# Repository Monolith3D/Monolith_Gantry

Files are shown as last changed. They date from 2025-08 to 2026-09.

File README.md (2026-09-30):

[][cc-by-nc-sa]

# Monolith Gantry R1
> [!IMPORTANT]
> **Step-by-step build guides for the printed and sheet metal versions are not yet available.**
> 
> **The sheet metal version is more difficult to build than what the average Voron user is used to. Please evaluate the required patience and skill levels before proceeding.**



## What's this?
This is a performance-oriented, configurable gantry platform for Voron 2.4 and Trident.

### [Official LDO Milled Gantry Kits](https://github.com/Monolith3D/LDO_Monolith_Gantry_Kits)

## Start Here

- [Gantry Configurator](https://configurator.monolith3d.xyz/) for configuration, files, and the selected BOM.
- [Build guides and assembly notes](Docs/)
- [Toolheads for Monolith](https://github.com/Monolith3D/Toolheads_for_Monolith) for compatible toolheads, belt clamps, and design guidelines.
- [FAQ](FAQ.md) for configuration, sourcing, and assembly questions.

### Drive configurations:
- 2WD
- AWD

### Belt widths:
- 6mm
- 9mm

 ### Materials:
- Printed
- Sheet metal
- Milled kits

## What's new with Monolith R1?
- Updated styling
- More shared parts between 6 and 9mm
- Sheet metal options
- Can fit into a stock 2020 frame at the cost of some Y-overtravel with the added no-protrusion mode
- Much better tensioner travel
- No toothed idlers
<br/>

> [!NOTE]
> **If you have questions or want to stay more up-to-date with Monolith, consider joining the dedicated Discord server.**
>
> Join the Discord (https://discord.gg/monolith3d)
>
> **If you would like to see more of this and other projects in the future, consider supporting Monolith on Patreon.**
>
> Support Monolith on Patreon (https://www.patreon.com/monolith3d)

## Design goals
- The shortest and the simplest belt path possible with AWD compatibility
- The shortest moment arms possible for increased rigidity even when reusing hardware and motion parts
- Double shear steppers and live shaft idlers for higher belt tensions and better reliability
- Good-looking design
- Cheap BOM

## Performance expectations
**2WD:** Due to the 10-15cm shorter belt path, with stiffer and lighter XY-joints the printer should perform similarly to a 50mm smaller one equipped with the same X-axis setup.

**AWD:** It doesn't come at the cost of adding 20cm belt length and idlers, so input shaper scaling can be close to +100% compared to 2WD due to the truly halved effective belt length. But only when no toolhead or frame bottlenecks are limiting its scaling.

**9mm belts:** Wider belts can offer an additional 50% input shaper scaling on top of what's described above.

## What's the catch?
- you have to build a well-balanced system: the increased effective belt stiffness with higher-end gantry configurations will amplify toolhead and frame rigidity issues
- Some toolheads are not yet compatible because of the different belt path
- Z-chain relocation or Z-umbilical is needed on V2
- Trident rear vertical extrusion brackets have to be rotated by 180 degrees or swapped to regular 2020 brackets based on the gantry configuration

## Acknowledgement
We want to thank:

- **[Sy-Noon](https://synoon.portfoliobox.net/)** for the awesome logo and feedback on general aesthetics
- **itsK** for the configurator website
- **ifp, iniqy, krankydonkey, MoneyShot, Nicket, tktktktk, Zakfarias, Scarecrow, The Adeo** for testing and good feedback
- **ZaMarin** and **Renovic** for the FAQ
- **Armchair Heavy Industries** for the exposure and the moderation help I got in their user-project space
- **VoronDesign** for making V2.4 and Trident and for starting us on this journey
- anyone who helped us along the way

<br/><br/><br/><br/>
This work is licensed under a
[Creative Commons Attribution-NonCommercial-ShareAlike 4.0 International License][cc-by-nc-sa].

[][cc-by-nc-sa]

[cc-by-nc-sa]: http://creativecommons.org/licenses/by-nc-sa/4.0/
[cc-by-nc-sa-image]: https://licensebuttons.net/l/by-nc-sa/4.0/88x31.png
[cc-by-nc-sa-shield]: https://img.shields.io/badge/License-CC%20BY--NC--SA%204.0-lightgrey.svg

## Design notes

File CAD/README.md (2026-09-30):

### The [Gantry Configurator](https://configurator.monolith3d.xyz/) will give you the links to the files you need for your build!

## Changelog

### 15.06.2025

- 695 W5 bearing support
- minor visual changes
- S45R long-shafted steppers in CAD
- subassembly fixes

### 10.06.2025

- sheet metal tensioner wire delete
- gantry-mounted X-endstop option

### 28.01.2025

- fixed subassembly origins
- fixed some naming oopsies
- ditched the printed alignment helpers for the sheet metal version
- more corner reliefs on motor mount plates
- smaller assembly/BOM fixes

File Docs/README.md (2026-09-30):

# Build guides and assembly notes

Step-by-step build guides for the printed and sheet metal R1 versions are not yet available. Use the [Gantry Configurator](https://configurator.monolith3d.xyz/) to select the configuration, files, and BOM for your build, and the [FAQ](../FAQ.md) for sourcing, print settings, and assembly notes.

Sheet metal builds require bearing-hole reaming, countersinking, and more involved assembly. Review the [printed and sheet metal comparison](../FAQ.md#should-i-choose-printed-or-sheet-metal) before choosing a build path.

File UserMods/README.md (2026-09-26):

# User Mods

This folder is for community-made additions, adaptations, and compatibility parts for the Monolith Gantry.

User mods are not official Monolith Gantry files unless stated otherwise. Check the mod author, target printer, gantry variant, drive layout, fit layout, and toolhead assumptions before printing or ordering parts.

Use the folder structure `username/usermod_name` for new user mods.

Good user mod folders should include:

- A short `README.md` explaining what the mod does
- Clear compatibility notes for V2 or VT, 2WD or AWD, and NP or FT where relevant
- STL, CAD, image, and BOM files needed to understand the mod
- Assembly notes or warnings if the mod changes belt path, endstops, travel, docks, panels, or toolhead clearance
- Credit and license notes when the mod reuses work from another project

Use user mods at your own risk. They may not receive updates when the main Monolith Gantry files change.

## Existing User Mods

| Mod | Author | What it does |
| --- | --- | --- |
| usermod_name | username | Briefly describe what the mod adds, adapts, or changes. |
| [Monolith cube](SilencedFrost/) | SilencedFrost | Provides a Monolith cube STL. |
| [X endstop extender and rear Z chain](OlBamboozler/) | OlBamboozler | Adds an Xol-carriage X endstop extender and a rear Z-chain extrusion mount for wiring cleanup. |
| [V2 MGN9C Z Joints](Iroh/V2%20MGN9C%20Z%20Joints/) | Iroh | Provides V2 Z-joint files for MGN9C Z rails/carriages, including printed, hybrid, and SLM files. |
| [SLM MGN12H XY-joints](CloakedWayne/SLM_MGN12H_XY_joints/) | CloakedWayne | Unmaintained, unsupported adaptation for MGN12H Y rails using SLM XY-joints. MGN9H carriages are recommended instead. |
| [XY Joints compatible with Fysetc CNC Stealthchanger Shuttle](dderg/XY%20Joints%20compatible%20with%20Fysetc%20CNC%20Stealthchanger%20Shuttle/) | dderg | Moves the X beam back 2 mm so 9 mm belts can clamp from the front of the Fysetc CNC Stealthchanger Shuttle. |
| [Monolith K1 Max](KhaymKhaym/Monolith%20K1%20Max/) | KhaymKhaym and BootyCallJones | Adapts the Monolith Gantry to the Creality K1 Max with CAD, panel DXF, gantry reinforcement DXF, and print files. |
| [Monolith VZ330](KhaymKhaym/Monolith%20VZ330/) | KhaymKhaym and Kaifas | Adapts the Monolith Gantry to the VZ330 with CAD-based assembly instructions. |
| [Sheet-Metal Monolith 3030 Mod](WolfKnifeLaserBacon/) | WolfKnifeLaserBacon | Adapts Sheet-Metal Monolith to 3030 Extrusions with CAD and BOM, changes required, etc |
|  | your name here :) |  |

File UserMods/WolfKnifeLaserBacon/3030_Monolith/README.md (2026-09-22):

# Monolith 3030 Sheet Metal Gantry

## Rat Rig V-Core 3.1 Modification

This user mod adapts the **Monolith gantry system** for use with a **Rat Rig V-Core 3.1** using a 3030-based sheet-metal gantry arrangement.

The current design is being developed around a **V-Core 3.1 500**, but other V-Core 3.1 sizes should be adaptable by changing the required extrusion, linear-rail, and belt lengths.

Most assembly procedures and hardware remain based on the standard Monolith BOM. This repository primarily contains the parts, dimensions, and hardware changes required to adapt Monolith to the V-Core 3.1 frame, along with additional information gathered during development.

For current development notes, reference information, and questions, see the dedicated Discord discussion:

💬 [Monolith V-Core 3.1 User Mod Development Thread](https://discord.com/channels/1227971059764953230/1537888786921427094)

---

## Current Status

- **Current printer:** Rat Rig V-Core 3.1 500
- **Drive configuration:** AWD
- **Gantry configuration:** Standard Monolith rail arrangement
- **X beam:** 594 mm
- **X MGN-12H linear rail:** 570 mm - Monolith standard
- **Y MGN-12C linear rails:** 550 mm - stock VC3.1
- **Development status:** Work in progress

The current release is designed around an **AWD Monolith configuration**.

A 2WD version will be adapted in a future revision.

No single toolhead has been selected as the required configuration. One of the goals of the project is to support multiple compatible toolhead and tool-changing options where practical.

---

# Design Direction

After spending considerably more time in CAD and experimenting with several different rail arrangements, the **standard Monolith rail configuration has proven to be the most practical and optimal solution for the V-Core 3.1**.

Several alternatives were investigated, including:

- Stock V-Core 3.1 Y-rail locations
- Top-mounted Y rails
- Bottom-mounted Y rails
- Mixed top/bottom Y-rail arrangements
- Top-mounted X rail

While some of these arrangements are technically possible, the required offsets, clearance compromises, loss of usable travel, increased complexity, and additional custom geometry outweigh their advantages.

In particular, a **top-mounted X rail is not a practical solution for this conversion** without introducing compromises that defeat much of the purpose of using Monolith in the first place.

Because of this, development will now focus solely on the **standard Monolith rail arrangement** rather than maintaining multiple substantially different gantry variants.

### Going forward, development will focus on:

- Standard Monolith rail geometry
- Different belt widths and belt configurations
- AWD
- 2WD adaptation
- Multiple toolhead options
- Tool changer compatibility
- Additional V-Core 3.1 frame sizes where practical
- Additional 3030 extrusion based printers

The goal is to refine one solid Monolith-based architecture rather than divide development between several compromised rail configurations.

---

# X Travel

One unavoidable difference between the stock V-Core 3.1 gantry and the Monolith 3030 conversion is the available X-axis travel.

For the **V-Core 3.1 500**:

| Configuration | X Linear Rail | Approximate X Travel |
| --- | ---: | ---: |
| Stock V-Core 3.1 | 600 mm | ~500–520 mm |
| Monolith 3030 | 570 mm | ~470 mm conservative |

The Monolith conversion therefore sacrifices approximately **30–50 mm of total X travel**, depending on the exact stock configuration and toolhead geometry.

The current **~470 mm** figure should be considered a conservative design target rather than an absolute mechanical limit.

Actual usable travel may vary slightly depending on:

- Toolhead
- X carriage
- Endstop arrangement
- Probe placement
- Tool changer hardware
- Belt attachment geometry
- Required frame and enclosure clearances

For most applications, the reduction in X travel is considered an acceptable tradeoff for maintaining the standard Monolith geometry and its associated simplicity, belt routing, rigidity, and performance.

Toolhead-specific travel information will be documented as configurations are tested.

---

# VC3.1 500 Dimensions

## Standard Monolith Configuration

This is the supported and actively developed configuration.

| Component | Length |
| --- | ---: |
| X beam | 594 mm |
| X linear rail | 570 mm |
| Y linear rails | 550 mm — stock VC3.1 |
| Rear extrusion | 510 mm |
| Expected X travel | ~470 mm conservative |

Additional dimensions will be added as the design is finalized and verified.

---

# BOM

Most hardware remains standard Monolith.

The following lists the hardware currently identified for the **3030 V-Core 3.1 conversion**.

## 9 mm Belt Configuration

### Belting

| Qty | Part |
| ---: | --- |
| 5.8m | 9 mm GT2 belt |

Final belt lengths will be added after the belt path and tensioning requirements have been finalized.

### Bearings, Pins, and Spacers

| Qty | Part |
| ---: | --- |
| 6 | 695 bearing |
| 24 | F695 flanged bearing |
| 2 | 0.2 mm shim |
| 22 | 0.5 mm shim |
| 14 | 1 mm shim |
| 6 | D5 × 40 smooth pin |
| 4 | D5 × 5 compression spring |
| 4 | M3 × D5 × 30 round standoff |
| 14 | M3 × D6 × 30 spacer |
| 2 | M5 × D10 × 5 shaft collar |
| 16 | M5 × D8 × 5 spacer |

### Pulleys

| Qty | Part |
| ---: | --- |
| 4 | GT2 20T 9 mm pulley |
| 4 | GT2 20T 9 mm pulley, de-hubbed |

### Set Screws and Nuts

| Qty | Part |
| ---: | --- |
| 8 | M4 × 2.5 set screw |
| 4 | M3 hex nut |

### M3 Hardware

| Qty | Part |
| ---: | --- |
| 24 | M3 washer |
| 8 | M3 × 4 BHCS |
| 20 | M3 × 6 BHCS |
| 6 | M3 × 6 FHCS |
| 6 | M3 × 8 BHCS |
| 2 | M3 × 8 FHCS |
| 4 | M3 × 40 BHCS |
| 14 | M3 × 45 BHCS |

### M5 Hardware

| Qty | Part |
| ---: | --- |
| 6 | M5 2020 T-nut |
| 8 | M5 washer |
| 6 | M5 × 8 BHCS |
| 2 | M5 × 30 BHCS |

### M6 / 3030 Specific Hardware

| Qty | Part |
| ---: | --- |
| 16 | M6 3030 T-nut |
| 16 | M6 washer |
| 16 | M6 × 10 BHCS |

---

## 10 mm Belt Configuration

A **10 mm belt configuration** is also planned.

### Belting

| Qty | Part |
| ---: | --- |
| TBD | 10 mm GT2 belt |

Additional pulley, bearing, spacer, and hardware requirements will be documented once the 10 mm configuration has been finalized and tested.

---

# Toolhead Compatibility

The 3030 Monolith conversion is not intended to be locked to a single toolhead.

Development will include evaluation and documentation of compatible toolhead configurations as they are modeled and tested.

Because toolhead geometry directly affects available travel, each supported configuration may have slightly different:

- Maximum X travel
- Maximum Y travel
- Probe clearance
- Endstop position
- Belt attachment position
- Frame clearance
- Docking clearance

Where possible, toolhead-specific travel limits and required parts will be documented separately.

---

# Tool Changer Compatibility

Tool changer compatibility is an active area of development.

The standard Monolith rail arrangement provides the most sensible foundation for investigating tool changing without creating separate gantry architectures for each configuration.

Future development may include:

- Tool docks
- Toolhead-specific carriages
- Dock mounting solutions
- Umbilical management
- CAN toolhead support
- Parking clearance
- Automatic tool changing
- Toolhead-specific travel limits

Tool changer support should currently be considered **experimental until individual configurations have been physically tested**.

---

# Compatibility

Currently designed around:

- Rat Rig V-Core 3.1
- 500 mm VC3.1 frame
- Standard Monolith gantry geometry
- AWD
- 3030 extrusion
- 9 mm GT2 belts
- 570 mm X linear rail
- 550 mm Y linear rails

Other V-Core 3.1 sizes should be adaptable by changing the appropriate extrusion, linear-rail, and belt lengths.

## Planned Development

Current development priorities include:

- 10 mm belts
- Additional belt configurations
- Additional toolhead options
- Tool changer compatibility
- 2WD adaptation
- Additional V-Core 3.1 frame sizes
- Verified travel measurements
- Final belt lengths
- Assembly documentation

Alternate top/bottom Y-rail arrangements and top-mounted X-rail configurations are **not currently planned for further development**.

---

# Assembly

Unless otherwise noted, assembly follows the standard Monolith assembly procedure and BOM.

Only components or assembly steps that differ from standard Monolith will be documented here.

Builders should verify:

- Belt alignment
- Pulley and bearing spacing
- Linear-rail alignment
- X/Y squareness
- Gantry clearance
- Toolhead clearance
- Endstop location
- Full X/Y travel

before operating the printer at high acceleration or speed.

---

# Initial ChatGPT Estimated Belt Length Comparison

| Belt configuration | Approximate length per belt | Approximate total for two belts |
|---|---:|---:|
| Stock Rat Rig V-Core 3.1 500 | 2,681 mm | 5,362 mm |
| 9 mm AWD arrangement | 2,589 mm | 5,178 mm |
| Difference | 92 mm shorter | 183 mm shorter |

The **9 mm AWD belts are approximately 3.4% shorter** than the stock Rat Rig V-Core 3.1 500 belts.

## Recommended Initial Cut Lengths

- **Stock V-Core 3.1 500:** approximately 2.70 m per belt
- **9 mm AWD arrangement:** approximately 2.61–2.62 m per belt

A **6 m roll of 9 mm GT2 belt** is sufficient for either configuration.

---

# Notes

This project is under active development.

Dimensions, hardware quantities, belt lengths, and CAD may change as the design is built and tested.

Parts marked **TBD** have not yet been finalized and should not be treated as manufacturing dimensions.

The **~470 mm X travel figure is currently a conservative estimate** for the V-Core 3.1 500 Monolith configuration. Final usable travel will depend partially on the selected toolhead and associated hardware.

If you build or adapt this mod for another V-Core 3.1 size, contributions, measurements, testing, and feedback are welcome.

Find me everywhere — literally — on Discord:

**WolfKnifeLaserBacon**

---

## Special Thanks

Special thanks to the [**Monolith community**](https://discord.gg/monolith3d) on Discord and to **CloakedWayne** for the development of the **Monolith gantry** — the de facto solution for speed, simplicity, and quality.

Additional thanks to:

- **Maurice** — Testing and confirmations
- **[your name here / USERNAME]** — [CONTRIBUTION]

The 3030 Monolith would not be where it is today without the ideas, feedback, testing, and support contributed along the way.

Thank you to everyone who helped turn the concept into a finished design.

---

## Support Me

**NOT required, but very much appreciated!!**

If you'd like to support my work and future development, you can do so through Ko-fi:

[Support me on Ko-fi](https://ko-fi.com/wolfknifelaserbacon)

Every bit of support helps with continued development, prototyping, testing, and future projects.

Thank you!

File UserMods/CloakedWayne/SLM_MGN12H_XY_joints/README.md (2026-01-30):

# SLM MGN12H XY-Joints
> [!WARNING]
> **This is only a deeply flawed user mod and a dead end, not an officially supported configuration. It won’t receive any updates. Do it at your own risk! You are definitely better off getting 9Hs for your build.**

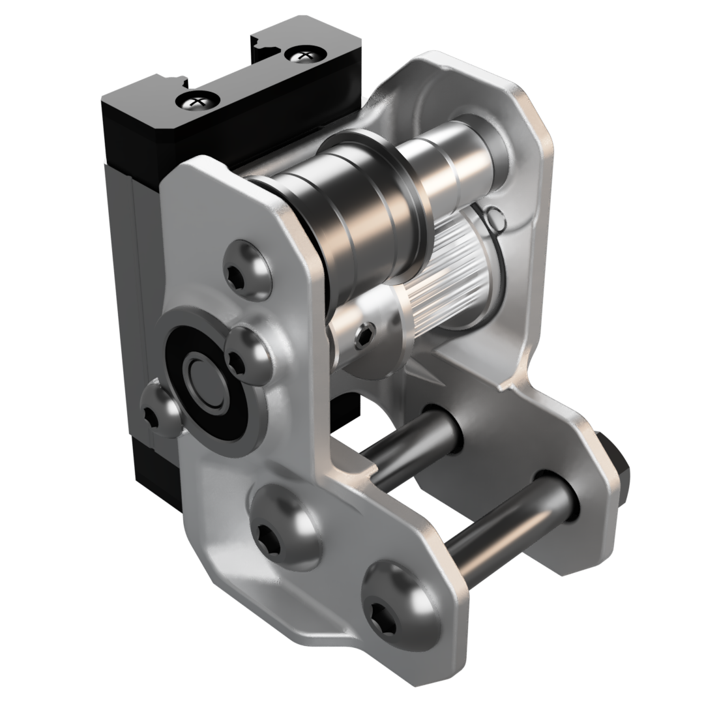
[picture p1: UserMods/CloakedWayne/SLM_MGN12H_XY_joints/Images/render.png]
Render

### Pros:
- You get MGN12Hs on Y with the unmodified Monolith belt path and without X-travel loss.
### Cons:
- Due to space constraints, the SLM part has to be really thin, and it’s very prone to warping.
- It requires a lot of post-processing, and you have to make sure the mounting surface is flat when it’s completely assembled.
- Hard to assemble and align.
- More severe bimetallic expansion, 2040 Y-extrusions, and/or backers are required.
- No performance advantage compared to MGN9H.
## Assembly

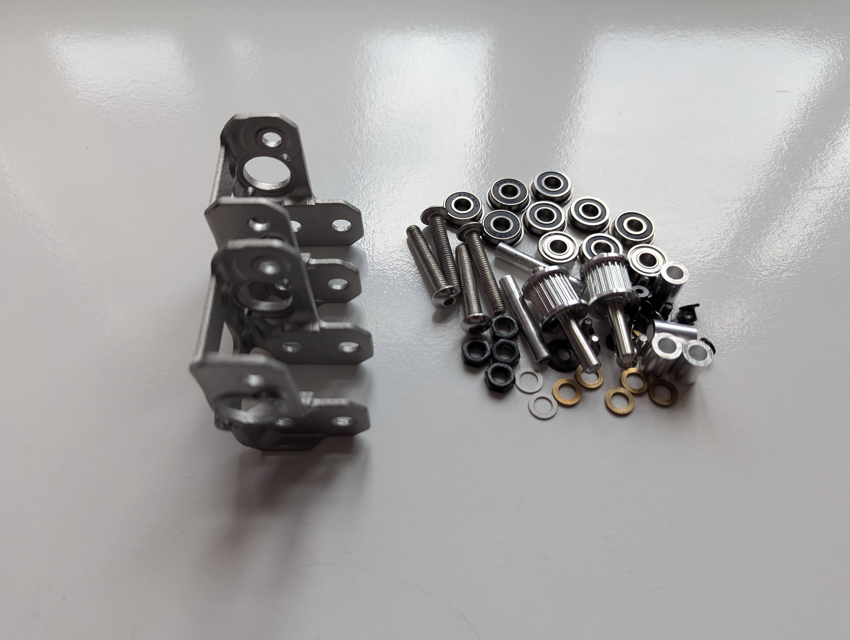
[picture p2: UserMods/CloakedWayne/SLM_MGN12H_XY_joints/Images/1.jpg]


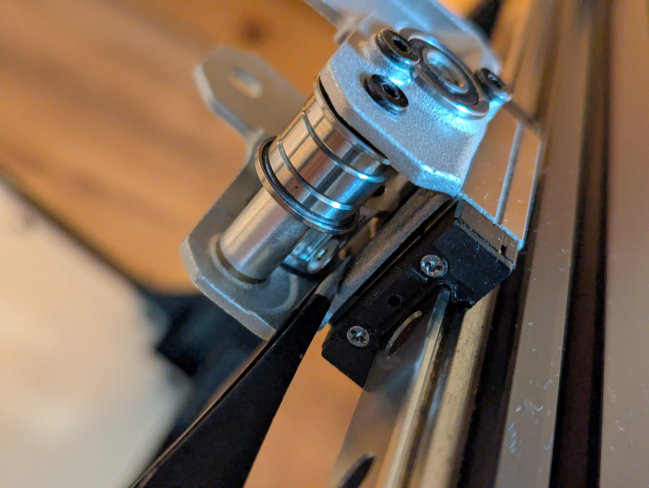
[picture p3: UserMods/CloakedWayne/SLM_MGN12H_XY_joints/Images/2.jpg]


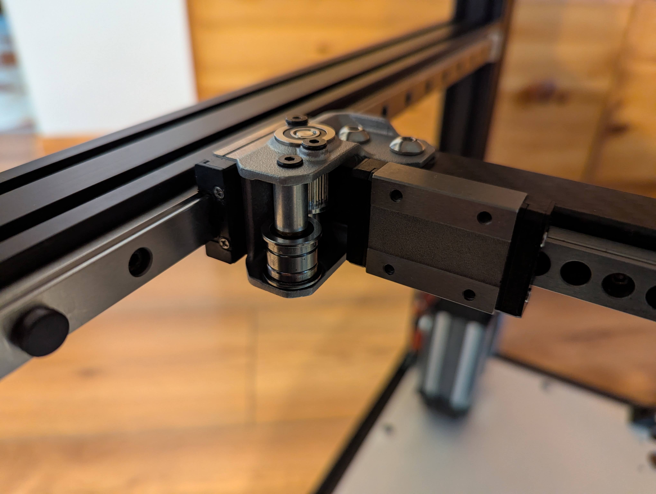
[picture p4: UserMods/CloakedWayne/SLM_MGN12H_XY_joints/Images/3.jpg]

## Vs. LDO MGN9H milled XY-joints in the same environment

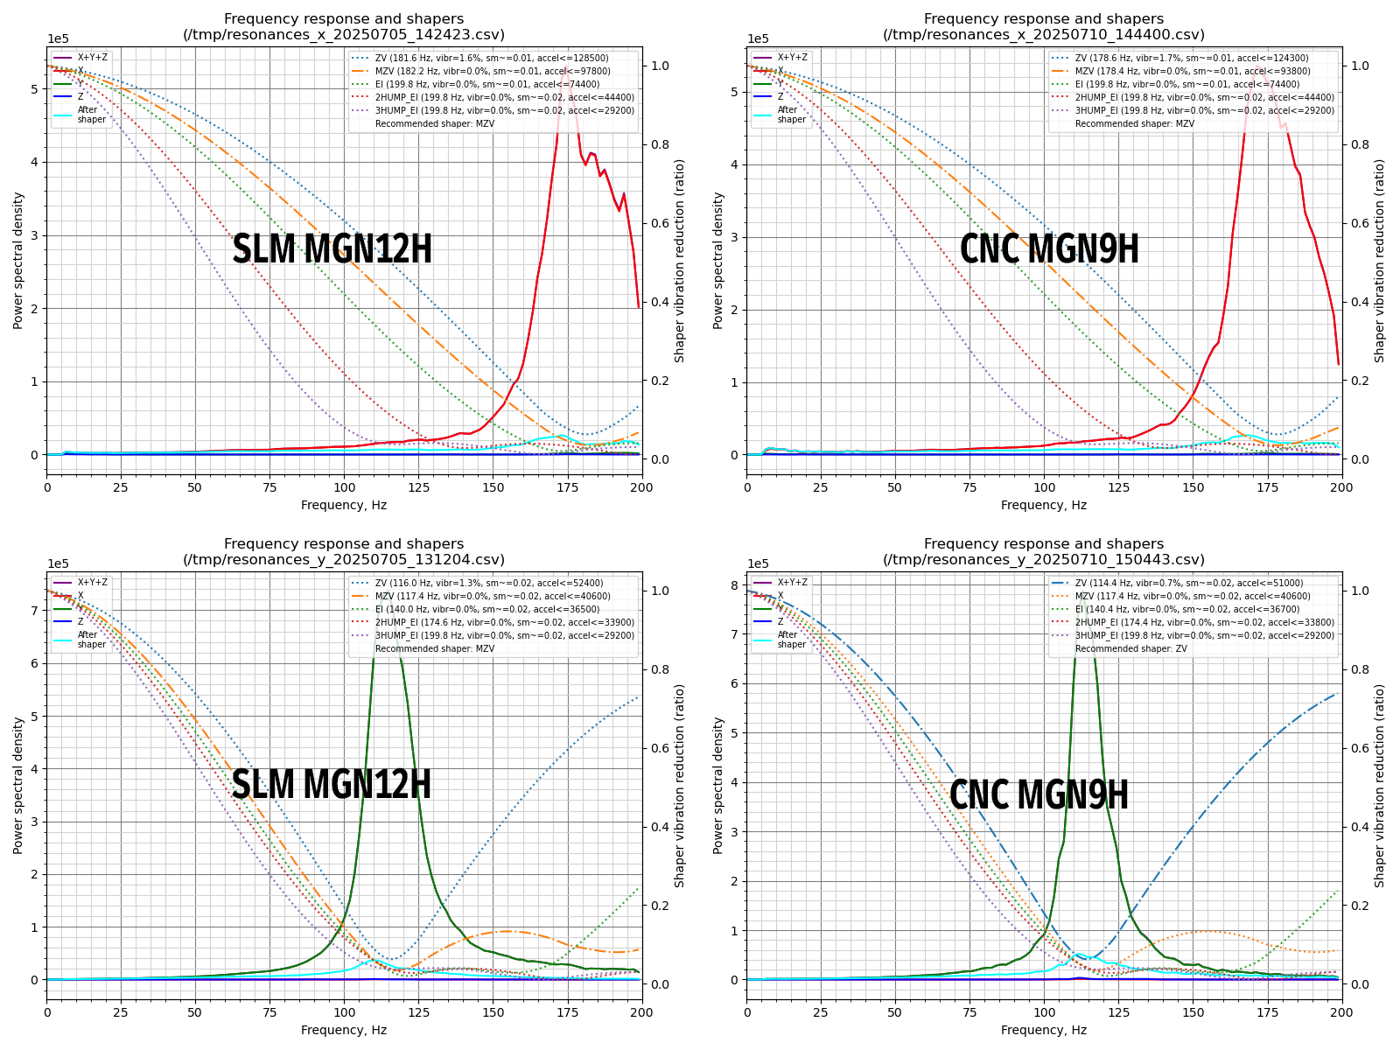
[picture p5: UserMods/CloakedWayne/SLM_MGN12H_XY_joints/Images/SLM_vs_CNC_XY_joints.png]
IS

## SLM orientation

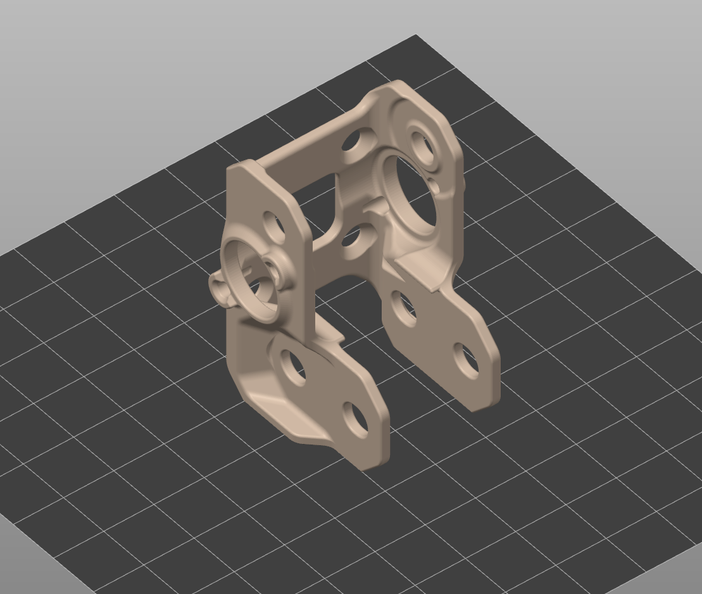
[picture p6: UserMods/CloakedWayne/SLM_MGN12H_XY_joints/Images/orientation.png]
Orientation

## BOM
| Quantity | Part Name |
| --- | --- |
| 2 | SLM MGN12H XY-joint |
| 8 | F695 flanged bearing | 
| 2 | 695 W5 bearing |
| 2 | M5x0.5mm shim |
| 8 | M3x5 FHCS |
| 2 | M3xD5x30 threaded round standoff |
| 8 | M3x4 BHCS |
| 4 | M3x6 BHCS |
| 8 | M5x1mm shim |
| 2 | D5x40 smooth pin |
| 6 | M5xD8x5 spacer |
| 2 | GT2 20T 9mm pulley de-hubbed |
| 4 | M4x2.5 set screw |
| 2 | Di=5mm L0=5mm compression spring |
| - | Mounting hardware for your X-beam |

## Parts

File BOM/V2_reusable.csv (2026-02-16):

Part Name | Quantity
2MGT 6mm belt | BOM amount
F695 flanged bearing | 20
GT2 20T 6mm pulley | 2
KW10 microswitch | 2
M2x10 self-tapping screw | 4
M3 2020 drop-in T-nut | 4
M3 washer | 2
M3x12 SHCS | 2
M3x16 SHCS | 9
M3x20 SHCS | 16
M3x30 BHCS | 12
M3x40 BHCS | 2
M3x6 FHCS | 6
M5 2020 drop-in T-nut | 27
M5 hex nut | 8
M5x10 BHCS | 11
M5x16 BHCS | 10
M5x30 BHCS | 10
M5x40 SHCS | 14
NEMA17 | 2
Shim 1mm | 22

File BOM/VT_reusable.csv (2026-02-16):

Part Name | Quantity
2MGT 6mm belt | BOM amount
F695 flanged bearing | 20
GT2 20T 6mm pulley | 2
KW10 microswitch | 2
M2x10 self-tapping screw | 4
M3 2020 drop-in T-nut | 3
M3 washer | 2
M3x12 SHCS | 1
M3x16 SHCS | 8
M3x30 BHCS | 8
M3x40 BHCS | 2
M3x6 FHCS | 8
M5 2020 drop-in T-nut | 29
M5 hex nut | 8
M5x10 BHCS | 24
M5x16 BHCS | 9
M5x30 BHCS | 6
M5x40 SHCS | 10
NEMA17 | 2
Shim 1mm | 22

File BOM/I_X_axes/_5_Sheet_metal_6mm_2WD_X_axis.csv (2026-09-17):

Part Name | Quantity
D5x30 smooth pin | 2
Di=5mm L0=5mm compression spring | 2
F695 flanged bearing | 8
GT2 20T 6mm pulley de-hubbed | 2
M3 hex nut | 4
M3 washer | 8
M3x30 BHCS | 4
M3x4 BHCS | 8
M3x6 BHCS | 12
M3xD5x20 threaded round standoff | 2
M4x2.5 set screw | 4
M5x8 BHCS | 6
M5xD8x5 spacer | 4
Sheet_metal_6mm_XY_joint_c_3-3.2mm | 2
Sheet_metal_XY_joint_a_3-3.2mm | 2
Sheet_metal_XY_joint_b_3-3.2mm | 2
Shim 0.2mm | 2
Shim 0.5mm | 6
Shim 1mm | 2

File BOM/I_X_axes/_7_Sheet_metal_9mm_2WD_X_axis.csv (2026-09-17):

Part Name | Quantity
695 bearing | 2
D5x40 smooth pin | 2
Di=5mm L0=5mm compression spring | 2
F695 flanged bearing | 8
GT2 20T 9mm pulley de-hubbed | 2
M3 hex nut | 4
M3 washer | 8
M3x4 BHCS | 8
M3x40 BHCS | 4
M3x6 BHCS | 12
M3xD5x30 threaded round standoff | 2
M4x2.5 set screw | 4
M5x12 BHCS | 6
M5xD8x5 spacer | 8
Sheet_metal_9mm_XY_joint_c_3-3.2mm | 2
Sheet_metal_9mm_spacer_a_2x2.5_or_5mm | 2
Sheet_metal_9mm_spacer_b_2x2.5_or_5mm | 2
Sheet_metal_9mm_spacer_c_2x2.5_or_5mm | 4
Sheet_metal_XY_joint_a_3-3.2mm | 2
Sheet_metal_XY_joint_b_3-3.2mm | 2
Shim 0.2mm | 2
Shim 0.5mm | 10
Shim 1mm | 4

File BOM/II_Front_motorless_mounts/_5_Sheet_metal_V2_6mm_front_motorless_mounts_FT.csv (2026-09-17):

Part Name | Quantity
D5x30 smooth pin | 2
Di=5mm L0=5mm compression spring | 2
F695 flanged bearing | 8
GT2 20T 6mm pulley | 2
Hybrid_SLM_V2_Z_belt_clip_a | 4
Hybrid_SLM_V2_Z_belt_clip_b | 4
M3x6 BHCS | 8
M3x8 BHCS | 8
M3xD5x20 threaded round standoff | 4
M5 2020 drop-in T-nut | 8
M5xD8x5 spacer | 4
Sheet_metal_V2_front_motorless_mount_a_4.7-5mm | 4
Shim 0.2mm | 2
Shim 0.5mm | 4
Shim 1mm | 6
_Hybrid_SLM_V2_6mm_Z_belt | 2

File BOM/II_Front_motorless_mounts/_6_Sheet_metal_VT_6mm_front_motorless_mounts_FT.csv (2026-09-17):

Part Name | Quantity
D5x30 smooth pin | 2
Di=5mm L0=5mm compression spring | 2
F695 flanged bearing | 8
GT2 20T 6mm pulley | 2
M3x6 BHCS | 8
M3x8 BHCS | 8
M3xD5x20 threaded round standoff | 4
M5 2020 drop-in T-nut | 8
M5x10 BHCS | 8
M5xD8x5 spacer | 4
Sheet_metal_VT_front_motorless_mount_a_4.7-5mm | 4
Shim 0.2mm | 2
Shim 0.5mm | 4
Shim 1mm | 6

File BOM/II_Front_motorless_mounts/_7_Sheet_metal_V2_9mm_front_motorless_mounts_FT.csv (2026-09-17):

Part Name | Quantity
695 bearing | 2
D5x40 smooth pin | 2
Di=5mm L0=5mm compression spring | 2
F695 flanged bearing | 8
GT2 20T 9mm pulley | 2
Hybrid_SLM_V2_Z_belt_clip_a | 4
Hybrid_SLM_V2_Z_belt_clip_b | 4
M3x6 BHCS | 8
M3x8 BHCS | 8
M3xD5x30 threaded round standoff | 4
M5 2020 drop-in T-nut | 8
M5xD8x5 spacer | 8
Sheet_metal_9mm_spacer_a_2x2.5_or_5mm | 4
Sheet_metal_V2_front_motorless_mount_a_4.7-5mm | 4
Shim 0.5mm | 6
Shim 1mm | 10
_Hybrid_SLM_V2_9mm_Z_belt | 2

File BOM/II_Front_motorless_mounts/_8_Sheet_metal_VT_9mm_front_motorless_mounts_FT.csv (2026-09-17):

Part Name | Quantity
695 bearing | 2
D5x40 smooth pin | 2
Di=5mm L0=5mm compression spring | 2
F695 flanged bearing | 8
GT2 20T 9mm pulley | 2
M3x6 BHCS | 8
M3x8 BHCS | 8
M3xD5x30 threaded round standoff | 4
M5 2020 drop-in T-nut | 8
M5 washer | 8
M5x16 BHCS | 8
M5xD8x5 spacer | 8
Sheet_metal_9mm_spacer_d_2x2.5_or_5mm | 4
Sheet_metal_VT_front_motorless_mount_a_4.7-5mm | 4
Shim 0.5mm | 6
Shim 1mm | 10

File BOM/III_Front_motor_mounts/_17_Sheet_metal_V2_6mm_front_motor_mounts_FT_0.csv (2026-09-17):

Part Name | Quantity
F695 flanged bearing | 6
GT2 20T 6mm pulley | 2
Hybrid_SLM_V2_Z_belt_clip_a | 4
Hybrid_SLM_V2_Z_belt_clip_b | 4
M3 washer | 8
M3x35 BHCS | 8
M3x6 BHCS | 4
M3x8 BHCS | 2
M3x8 FHCS | 2
M3xD5x20 threaded round standoff | 2
M3xD6x20 spacer | 8
M5 2020 drop-in T-nut | 8
M5xD8x5 spacer | 4
Sheet_metal_V2_front_motor_mount_a_4.7-5mm | 2
Sheet_metal_V2_front_motor_mount_b_4.7-5mm | 2
Shim 0.5mm | 4
Shim 1mm | 2
_Hybrid_SLM_V2_6mm_Z_belt | 2
_S45R shaft | 2
_stepper | 2

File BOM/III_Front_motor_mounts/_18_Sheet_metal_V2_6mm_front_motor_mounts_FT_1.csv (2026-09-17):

Part Name | Quantity
F695 flanged bearing | 6
GT2 20T 6mm pulley | 2
Hybrid_SLM_V2_Z_belt_clip_a | 4
Hybrid_SLM_V2_Z_belt_clip_b | 4
M3 washer | 8
M3x35 BHCS | 8
M3x6 BHCS | 2
M3x8 BHCS | 2
M3x8 FHCS | 4
M3xD5x20 threaded round standoff | 2
M3xD6x20 spacer | 8
M5 2020 drop-in T-nut | 8
M5xD8x5 spacer | 4
Sheet_metal_6mm_spacer_b_2_or_2.5mm | 1
Sheet_metal_V2_front_motor_mount_a_4.7-5mm | 2
Sheet_metal_V2_front_motor_mount_b_4.7-5mm | 2
Shim 0.5mm | 4
Shim 1mm | 2
_Hybrid_SLM_V2_6mm_Z_belt | 2
_S45R shaft | 1
_standard shaft | 1
_stepper | 2

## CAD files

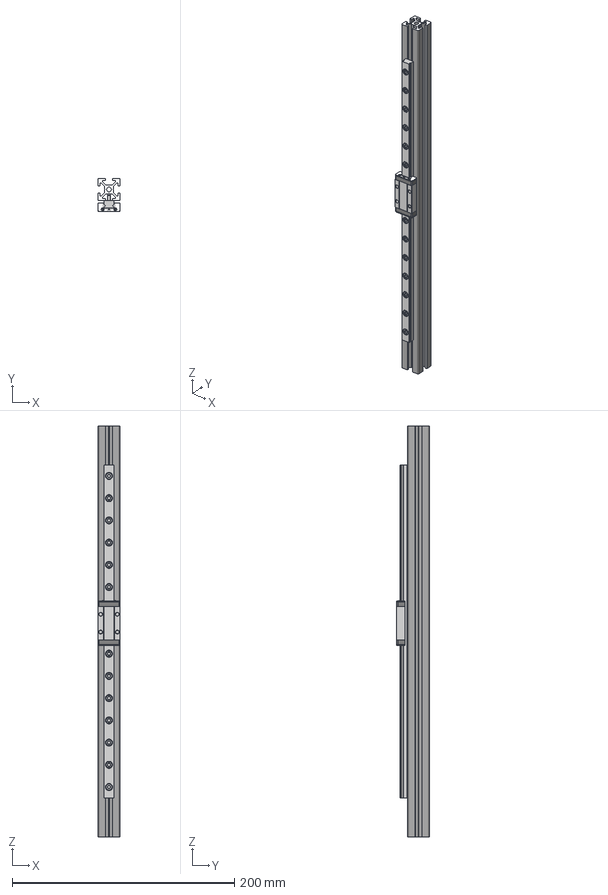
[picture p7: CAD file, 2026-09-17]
CAD/XI_Frames/_VT_Y_extrusion_assembly.step
20.0 x 30.0 x 370.0 mm

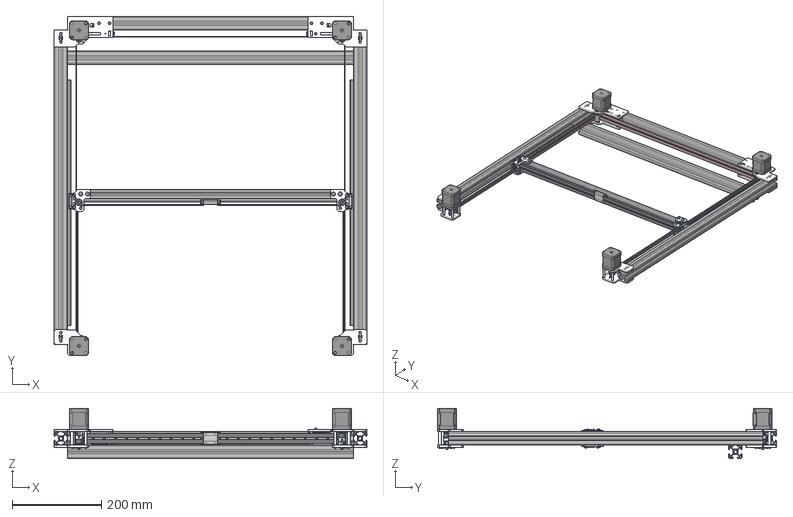
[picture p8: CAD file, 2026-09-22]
UserMods/WolfKnifeLaserBacon/3030_Monolith/Standard Monolith Assemblies/3030 Monolith - Standard - Assembled.step
700.0 x 759.1 x 112.0 mm

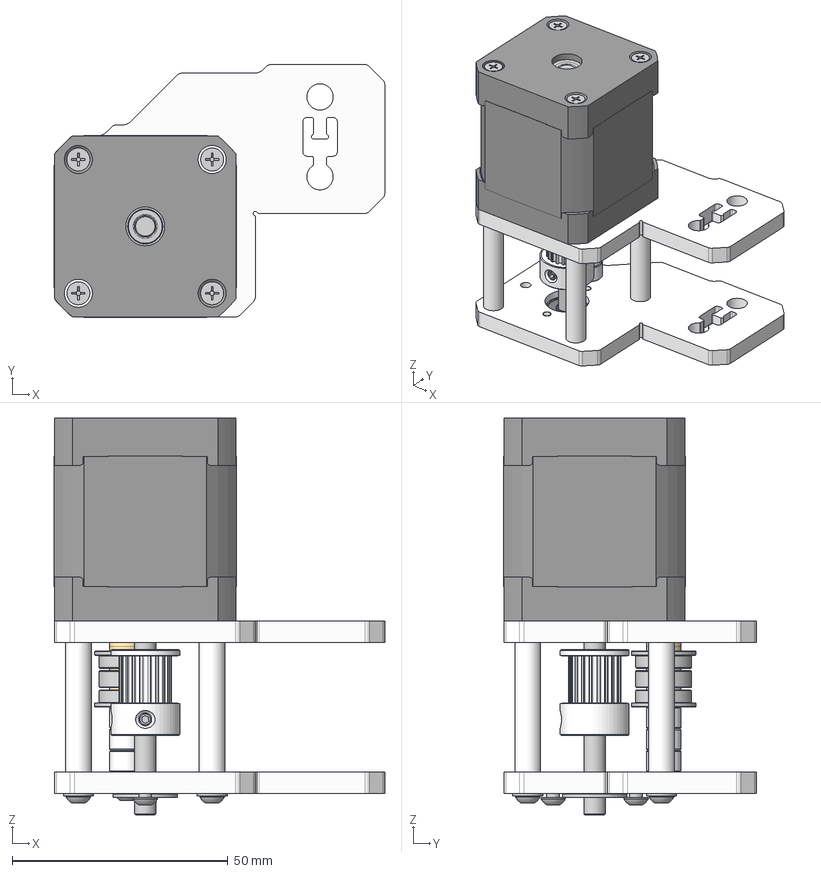
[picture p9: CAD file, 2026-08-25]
UserMods/WolfKnifeLaserBacon/3030_Monolith/Standard Monolith Assemblies/Front Motor Assemblies/3030 Front Right Motor Assembly.step
76.6 x 58.6 x 92.0 mm
M3xD6x30 spacer (2) x 4
M3x6 BHCS (3) x 2
M3 washer (3) x 4
M3x8 BHCS (2)
M3x45 BHCS (2) x 4
M3x8 FHCS (1)
M3xD5x30 threaded round standoff (2)
F695 flanged bearing (3) x 3
M5xD8x5 spacer (3) x 3
Shim 0.5mm (3) x 2
Shim 1mm (3) x 2
695 bearing (3)
GT2 20T 9mm pulley (2)
_S45R shaft (2)
_stepper (2)

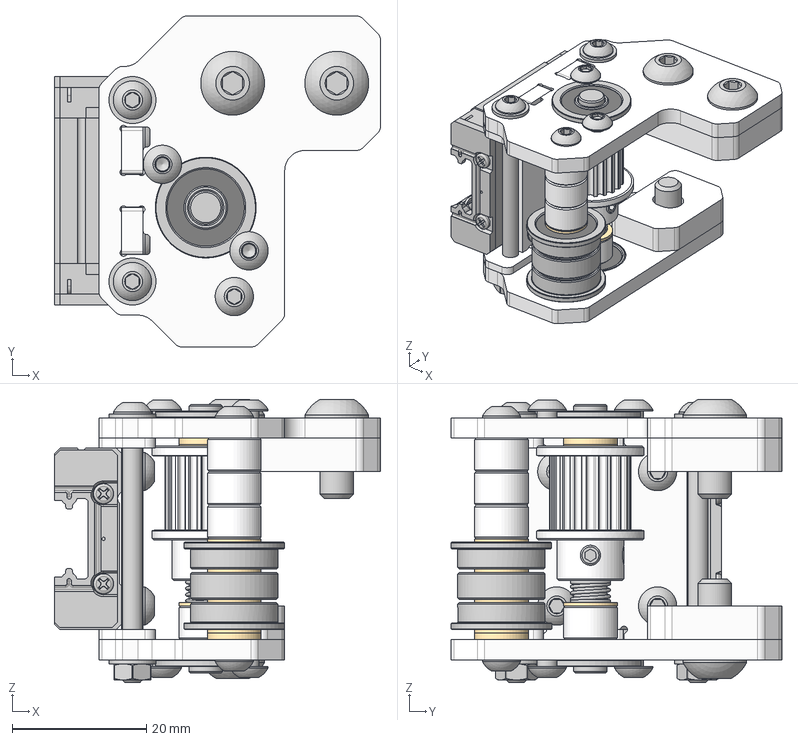
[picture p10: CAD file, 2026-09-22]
UserMods/WolfKnifeLaserBacon/3030_Monolith/Standard Monolith Assemblies/X Axis Assemblies/3030 Left XY Joint Assembly.step
48.5 x 49.2 x 42.2 mm
9184T713_Maintenance-Free Ball Bearing Carriage

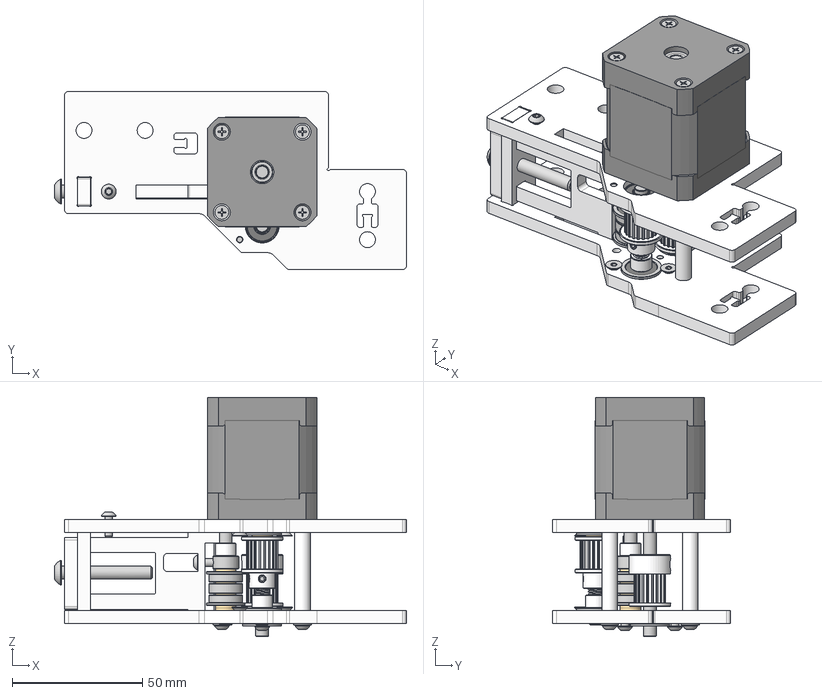
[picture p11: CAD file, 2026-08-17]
UserMods/WolfKnifeLaserBacon/3030_Monolith/Standard Monolith Assemblies/Y Axis Assemblies/3030 Rear Right Motor Assembly.step
135.4 x 68.5 x 92.0 mm

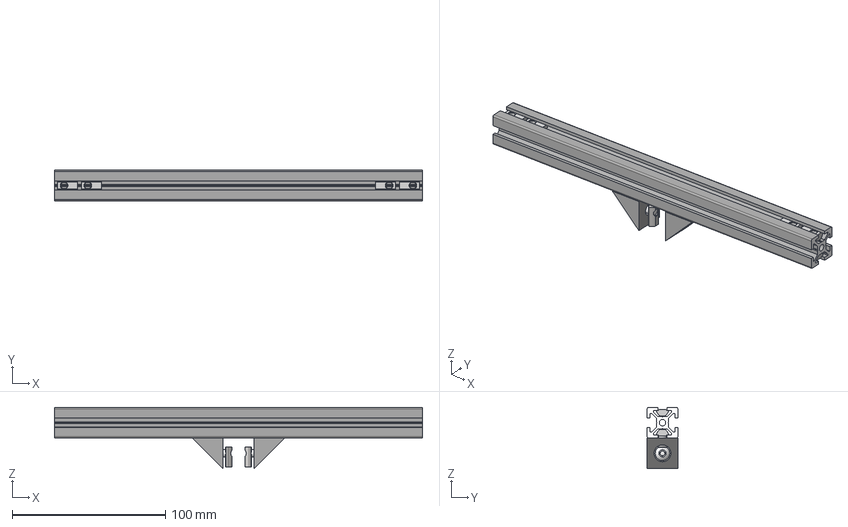
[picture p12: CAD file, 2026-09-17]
CAD/XI_Frames/_Rear_extrusion_assembly_VT_NP.step
240.0 x 20.0 x 40.0 mm
M5x8 BHCS x 4
2020_corner_bracket x 2
M5 2020 drop-in T-nut x 4

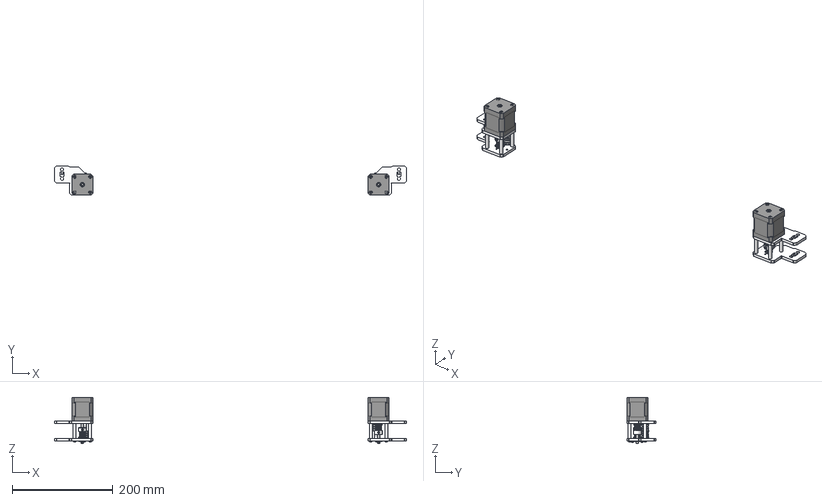
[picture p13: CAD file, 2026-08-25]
UserMods/WolfKnifeLaserBacon/3030_Monolith/Standard Monolith Assemblies/Front Motor Assemblies/3030 Front Motor Assemblies.step
700.0 x 58.6 x 92.0 mm
M3xD6x30 spacer (2) x 4
M3x6 BHCS (3) x 2
M3 washer (3) x 4
M3x8 BHCS (2)
M3x45 BHCS (2) x 4
M3x8 FHCS (1)
M3xD5x30 threaded round standoff (2)
F695 flanged bearing (3) x 3
M5xD8x5 spacer (3) x 3
Shim 0.5mm (3) x 2
Shim 1mm (3) x 2
695 bearing (3)
GT2 20T 9mm pulley (2)
_S45R shaft (2)
_stepper (2)

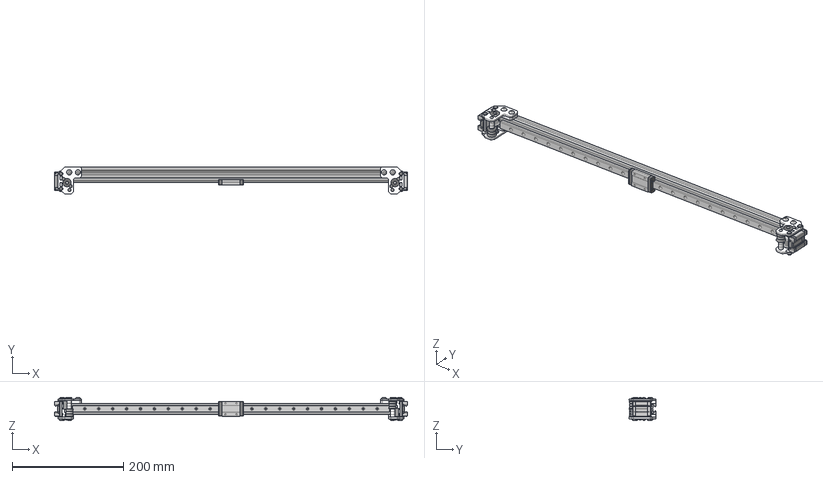
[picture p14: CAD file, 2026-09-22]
UserMods/WolfKnifeLaserBacon/3030_Monolith/Standard Monolith Assemblies/X Axis Assemblies/3030 X Axis Assembly.step
634.0 x 49.2 x 42.2 mm
9184T713_Maintenance-Free Ball Bearing Carriage

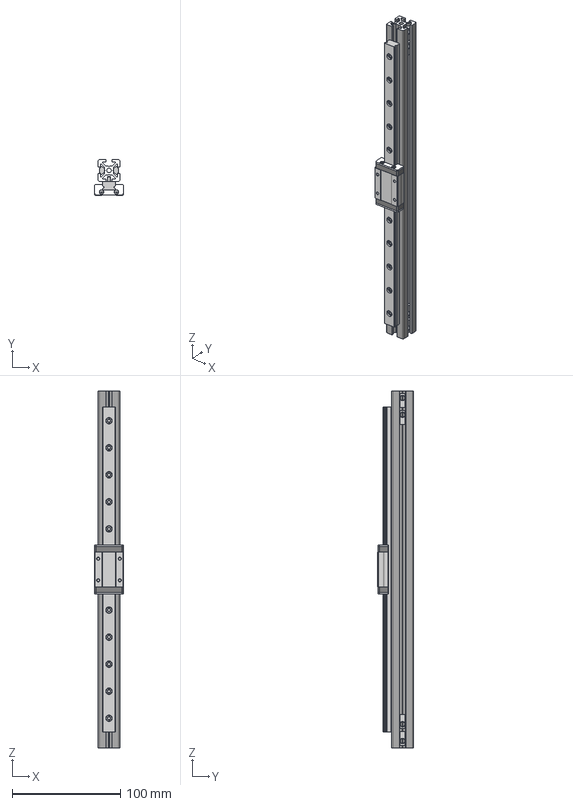
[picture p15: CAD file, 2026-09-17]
CAD/XI_Frames/_X-extrusion_assembly.step
27.0 x 33.0 x 330.0 mm

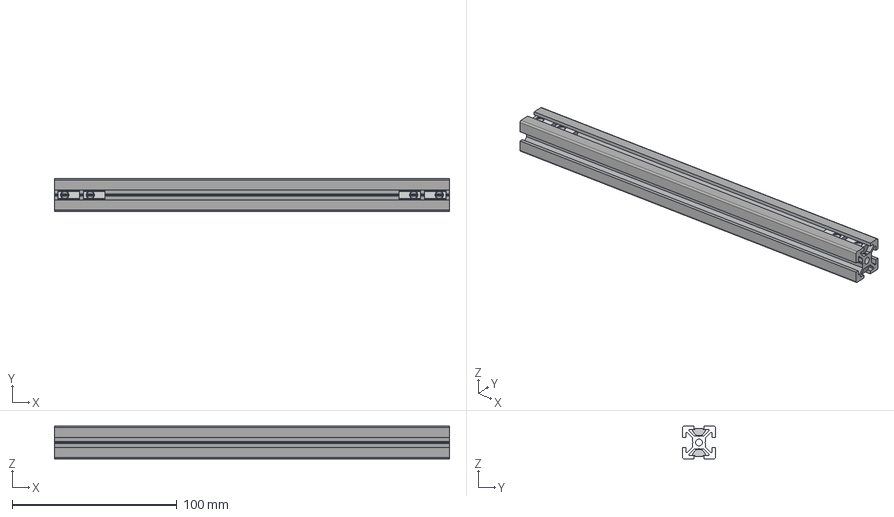
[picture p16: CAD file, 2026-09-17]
CAD/XI_Frames/_Rear_extrusion_assembly_V2_NP.step
240.0 x 20.0 x 20.0 mm

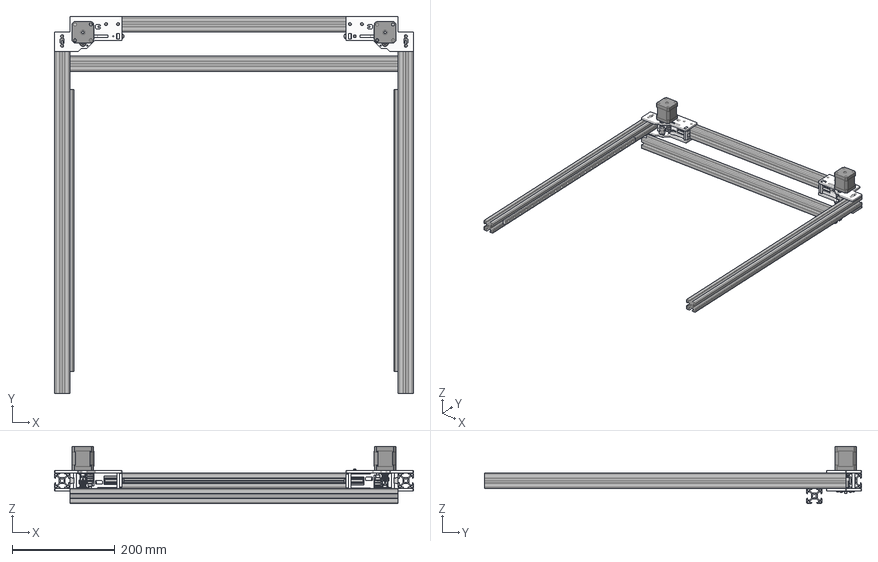
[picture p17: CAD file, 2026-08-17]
UserMods/WolfKnifeLaserBacon/3030_Monolith/Standard Monolith Assemblies/Y Axis Assemblies/3030 Complete Y Assembly.step
700.0 x 735.0 x 112.0 mm

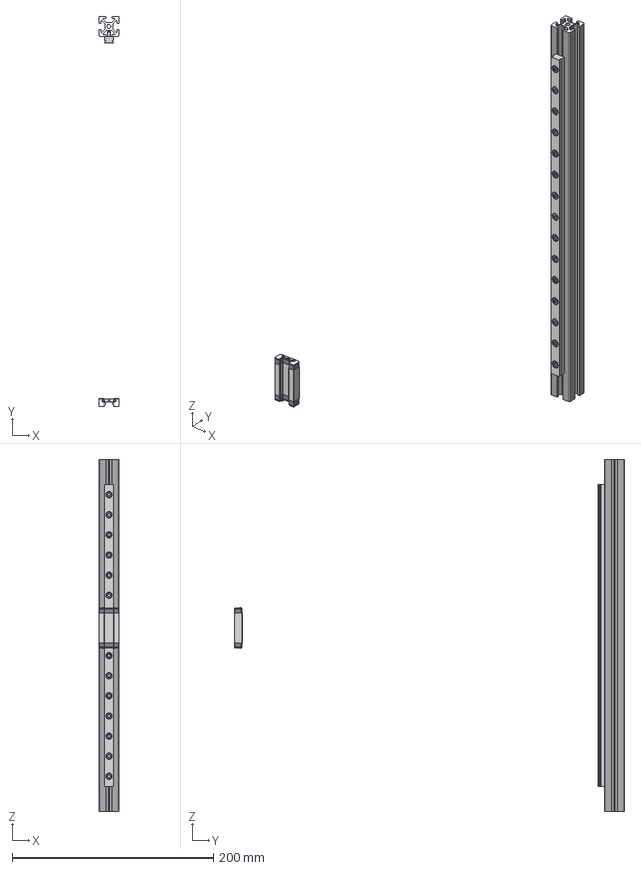
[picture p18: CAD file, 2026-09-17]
CAD/XI_Frames/_V2_Y_extrusion_assembly.step
20.0 x 388.0 x 350.0 mm

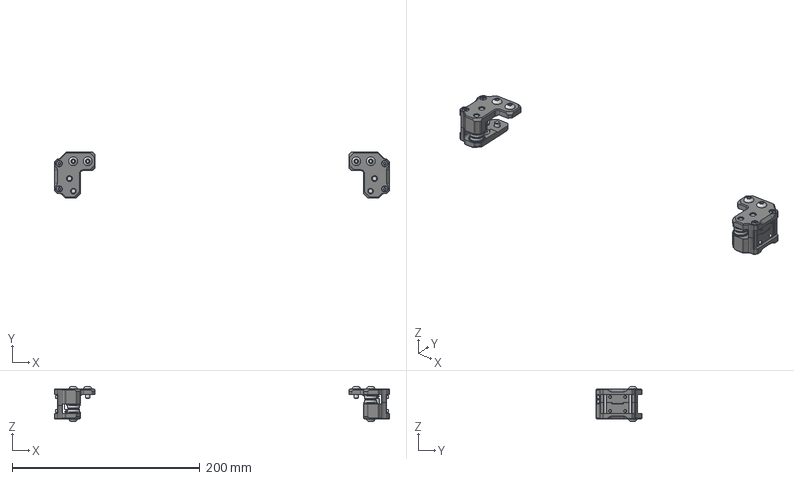
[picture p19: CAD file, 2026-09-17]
CAD/I_X_axes/_2_Printed_6mm_AWD_X_axis.step
356.8 x 49.2 x 37.5 mm

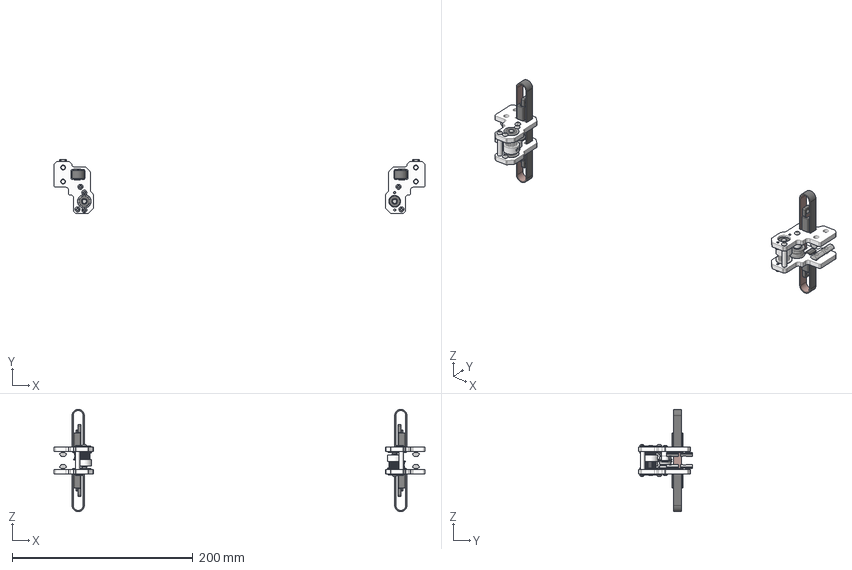
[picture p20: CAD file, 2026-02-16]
CAD/II_Front_motorless_mounts/_5_Sheet_metal_V2_6mm_front_motorless_mounts_FT.step
410.0 x 59.6 x 113.1 mm
Sheet_metal_V2_front_motorless_mount_a_4.7-5mm x 4
M3xD5x20 threaded round standoff x 4
D5x30 smooth pin x 2
Shim 0.5mm x 4
Shim 1mm x 6
F695 flanged bearing x 8
GT2 20T 6mm pulley x 2
M5xD8x5 spacer x 4
Di=5mm L0=5mm compression spring x 2
Shim 0.2mm x 2
M3x8 BHCS x 8
M3x6 BHCS x 8
M5 2020 drop-in T-nut x 8
_Hybrid_SLM_V2_6mm_Z_belt x 2
Hybrid_SLM_V2_Z_belt_clip_a x 4
Hybrid_SLM_V2_Z_belt_clip_b x 4

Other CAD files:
UserMods/WolfKnifeLaserBacon/3030_Monolith/Standard Monolith Assemblies/Front Motor Assemblies/3030 Front Left Motor Assembly.step
UserMods/WolfKnifeLaserBacon/3030_Monolith/Standard Monolith Assemblies/X Axis Assemblies/3030 Right XY Joint Assembly.step
UserMods/WolfKnifeLaserBacon/3030_Monolith/Standard Monolith Assemblies/Y Axis Assemblies/3030 Rear Left Motor Assembly.step
CAD/XI_Frames/_Rear_extrusion_assembly_FT.step
CAD/III_Front_motor_mounts/_17_Sheet_metal_V2_6mm_front_motor_mounts_FT_0.step
CAD/III_Front_motor_mounts/_18_Sheet_metal_V2_6mm_front_motor_mounts_FT_1.step
CAD/III_Front_motor_mounts/_19_Sheet_metal_V2_6mm_front_motor_mounts_FT_2.step
CAD/III_Front_motor_mounts/_20_Sheet_metal_V2_6mm_front_motor_mounts_NP_0.step
CAD/III_Front_motor_mounts/_21_Sheet_metal_V2_6mm_front_motor_mounts_NP_1.step
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

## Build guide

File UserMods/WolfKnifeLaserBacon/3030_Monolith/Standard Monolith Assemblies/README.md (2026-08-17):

# 3030 Monolith - Standard Monolith Assemblies

Standard Monolith gantry assemblies adapted for use with 3030 extrusions.

## Purpose

This folder contains the standard Monolith-style assembly configuration for the 3030 Monolith project.

## Notes

- Uses standard Monolith gantry geometry where possible.
- Adapted for 3030 extrusion-based builds.
- Intended to remain as close to the standard Monolith BOM and assembly layout as practical.
- Printer-specific modifications may be required depending on frame size and rail placement.

## Contents

This folder may contain:

- CAD files
- STL files
- DXF files
- Assembly files
- Variant-specific documentation

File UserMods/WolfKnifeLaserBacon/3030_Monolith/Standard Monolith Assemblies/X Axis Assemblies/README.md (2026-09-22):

# X/Y Joint & X-Axis Assemblies

STEP files for the 3030 Monolith X/Y joint and X-axis assemblies.

## Files

- `3030 Left XY Joint Assembly.step`  
  Left-side X/Y joint assembly.

- `3030 Right XY Joint Assembly.step`  
  Right-side X/Y joint assembly.

- `3030 X Axis Assembly.step`  
  Complete X-axis assembly.

## Notes

Carriage model used is a 12C

These files are intended for the 3030 Monolith gantry configuration.

The left and right X/Y joint assemblies are provided separately for easier reference, modification, and integration into larger CAD assemblies.

The complete X-axis assembly can be used to verify overall fitment, rail placement, and component relationships before installation.

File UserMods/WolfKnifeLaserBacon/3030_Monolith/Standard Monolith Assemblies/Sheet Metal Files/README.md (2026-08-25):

# Sheet Metal Parts

This folder contains the sheet metal components required for the **3030 Monolith gantry**.

These parts are intended to be sent to a sheet metal fabrication service for cutting and forming before assembly.

---

# Ordering Instructions

## Understanding the File Names

The STEP file names include important information about:

- Required **total** quantity
- Part name
- Acceptable material thickness
- Required finished stack thickness

**Please read the file name carefully before ordering.**

There are two different thickness conventions used in this folder:

1. **Thickness options** — either listed thickness is acceptable.

2. **Specified thickness** — the listed thickness is required to achieve the correct assembled stack height. For parts requiring a **5 mm total thickness**, two **2.5 mm parts may be stacked together**. This is often preferable because the closest commonly available single-sheet option is **4.7 mm**, which does not provide the required stack height, while **2.5 mm material is typically readily available**.

These are not interchangeable.

---

## Quantity Prefix

The quantity shown with each file indicates the **total number of finished parts required**.

For example:

```text
2x Sheet_metal_9mm_tensioner_c_4.7-5mm.step
```

This means:

- Order **2 pieces**
- Each piece may be made from either **4.7 mm or 5.0 mm material**
- Both thicknesses are acceptable for this component

Additionally, parts listed without a leading quantity should have a quantity and thickness listed near the end of the filename. 

For example:

```text
Sheet_metal_9mm_spacer_a_4x2.5mm_or_2x5mm.step
```

This means:

- Order **4 pieces at 2.5mm OR 2 pieces at 5mm**
- Both thicknesses are acceptable for this component at the quantity listed

Different fabrication services offer different standard material thicknesses, so the files allow either option where appropriate.

---

### Combined Spacer Part

The following individual spacer file is required at **4x pieces, 1.5 mm thick each**:

`Sheet_metal_9mm_spacer_c_1.5mm.step`

Because these parts are relatively small, some fabrication services may not be able to manufacture them individually due to minimum part-size requirements.

For that reason, the following combined version is also provided:

`Combined_Sheet_metal_9mm_spacer_c_1.5mm.step`

The combined file joins the required spacers together with small connecting tabs so the assembly can be ordered as one larger part.

After fabrication:

- Cut the individual spacers apart at the connecting tabs.
- File or sand the remaining connection points smooth.
- Remove any burrs before assembly.
- Verify that the finished spacers remain flat.

The combined file is only a **manufacturing convenience** and does not change the required final spacer thickness or quantity.

*At this time, the closest option is 1.6mm thickness. Testing will determine if this is allowable or if further post processing is required.* 

---

## Questions / Discord

If you have questions about the **3030 Monolith conversion**, sheet metal ordering, assembly, fitment, or current development, you can usually find me on Discord as:

**WolfKnifeLaserBacon**

You can find me in the **[Monolith Discord](https://discord.gg/monolith3d)** or in the dedicated **[3030 Monolith Development Thread](https://discord.com/channels/1227971059764953230/1537888786921427094)**.

I’m happy to help clarify file requirements, ordering details, assembly questions, or anything else that comes up during your build.

**Don’t be shy — your question may prompt an addition to this README and earn you a nice special thanks in the main README!**

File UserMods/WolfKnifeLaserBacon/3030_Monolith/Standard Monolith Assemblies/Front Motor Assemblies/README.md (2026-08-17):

# Front Motor Assembly

STEP files for the 3030 Monolith front motor assemblies.

## Files

- `3030 Front Left Motor Assembly.step`  
  Left-side front motor assembly.

- `3030 Front Motor Assemblies.step`  
  Complete front motor assembly containing both left and right sides.

- `3030 Front Right Motor Assembly.step`  
  Right-side front motor assembly.

## Notes

These files are intended for the 3030 Monolith gantry configuration and can be used for reference, modification, or integration into larger CAD assemblies.

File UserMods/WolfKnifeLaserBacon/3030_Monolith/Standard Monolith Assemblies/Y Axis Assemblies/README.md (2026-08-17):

# Y-Axis & Rear Motor Assemblies

STEP files for the 3030 Monolith Y-axis, frame extrusion, and rear motor assemblies.

## Files

- `3030 Complete Y Assembly.step`  
  Complete Y-axis assembly.

- `3030 Extrusions.step`  
  3030 extrusion layout used for the gantry assembly.

- `3030 Rear Left Motor Assembly.step`  
  Left-side rear motor assembly.

- `3030 Rear Right Motor Assembly.step`  
  Right-side rear motor assembly.

## Notes

These files are intended for the 3030 Monolith gantry configuration.

The complete Y assembly can be used to verify overall fitment, rail placement, motor positioning, and component relationships.

Left and right rear motor assemblies are also provided separately for easier reference, modification, and integration into larger CAD assemblies.

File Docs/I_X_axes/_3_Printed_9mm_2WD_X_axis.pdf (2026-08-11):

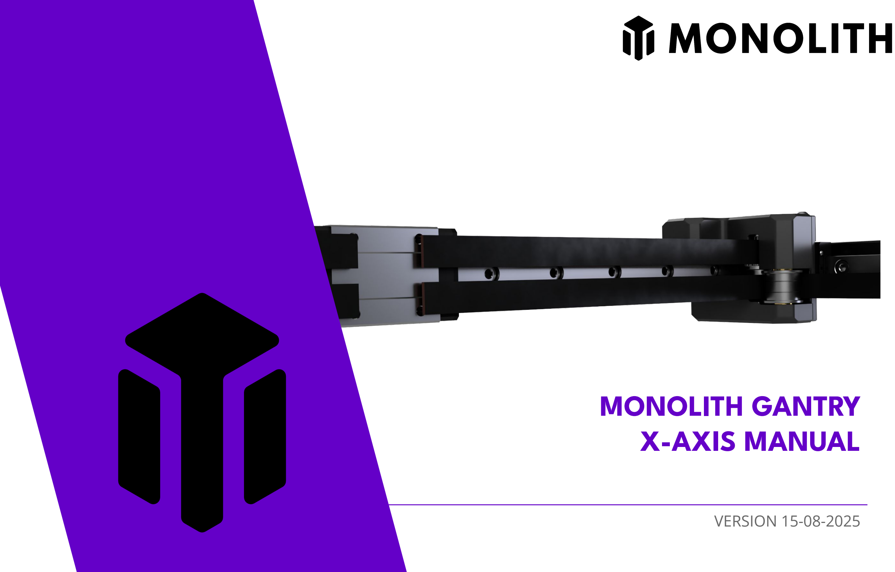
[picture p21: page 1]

# MONOLITH GANTRY X-AXIS MANUAL

# VERSION 15-08-2025

# MONOLITH DISCLAIMER

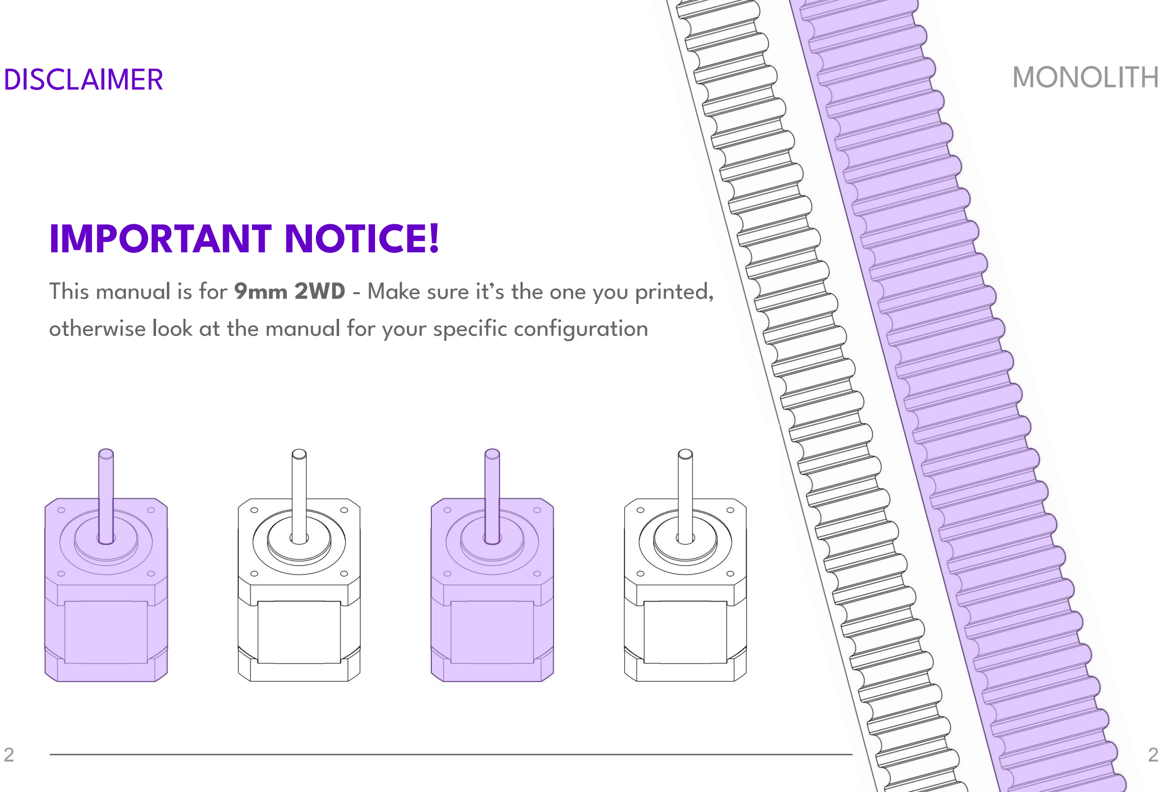
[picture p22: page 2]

2

# IMPORTANT NOTICE!

This manual is for 9mm 2WD - Make sure it’s the one you printed,

## otherwise look at the manual for your specific configuration

2

# MONOLITH

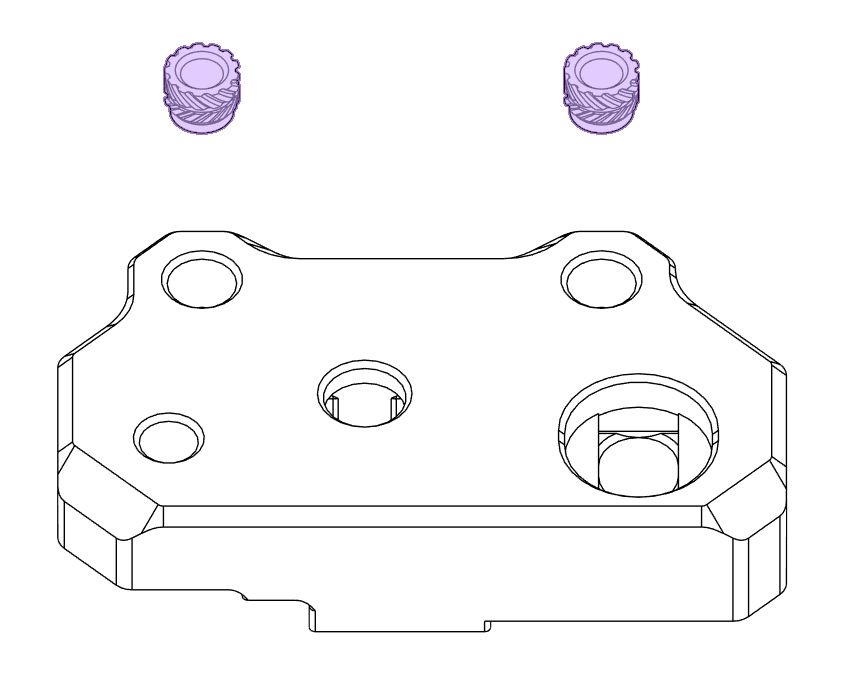
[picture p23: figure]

INSTALL HEAT SET INSERTS x4
The two bottom parts need M3 heat set inserts, four inserts total. The bottom parts are the “rectangular” ones, not the “L shaped” ones

# PREPARING THE PARTS

M3 Heat Set Insert

# MONOLITH

INSERT LIVE SHAFT BEARINGS x4
For all four printed parts you need to press in a F695 bearing, be sure to make it go all the way

# PREPARING THE PARTS

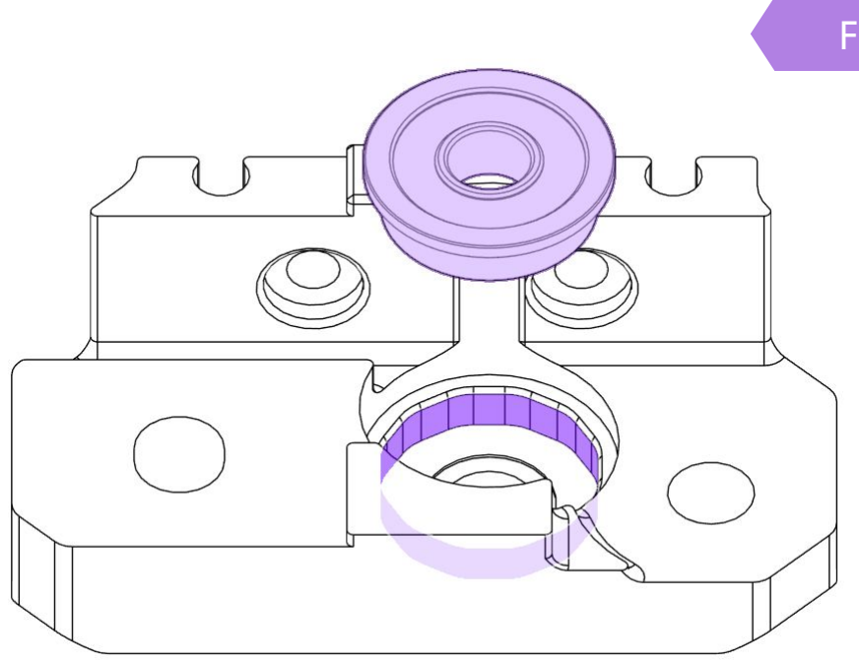
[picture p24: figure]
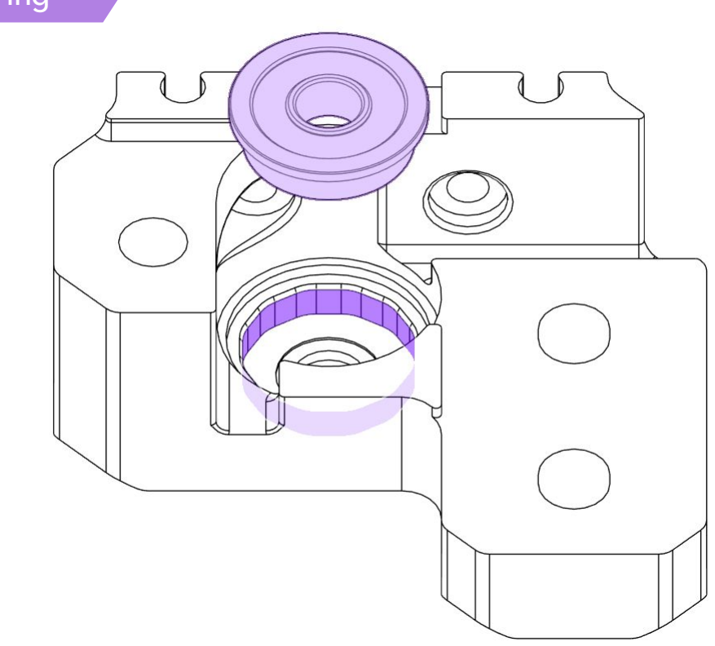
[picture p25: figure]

F695 Bearing

FIRST HALVES | MONOLITH

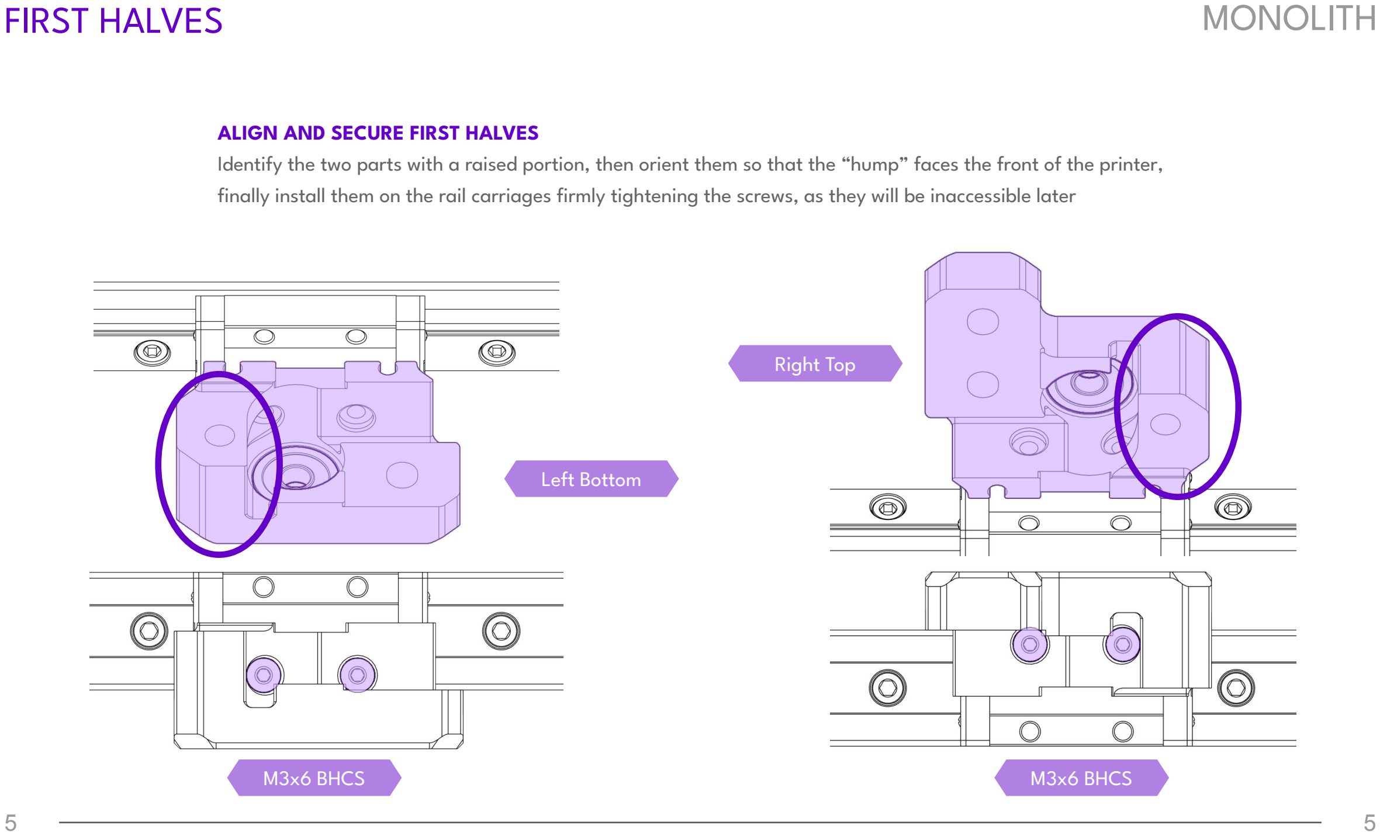
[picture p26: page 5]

ALIGN AND SECURE FIRST HALVES
Identify the two parts with a raised portion, then orient them so that the “hump” faces the front of the printer, finally install them on the rail carriages firmly tightening the screws, as they will be inaccessible later
M3x6 BHCS | M3x6 BHCS

Left Bottom

Right Top

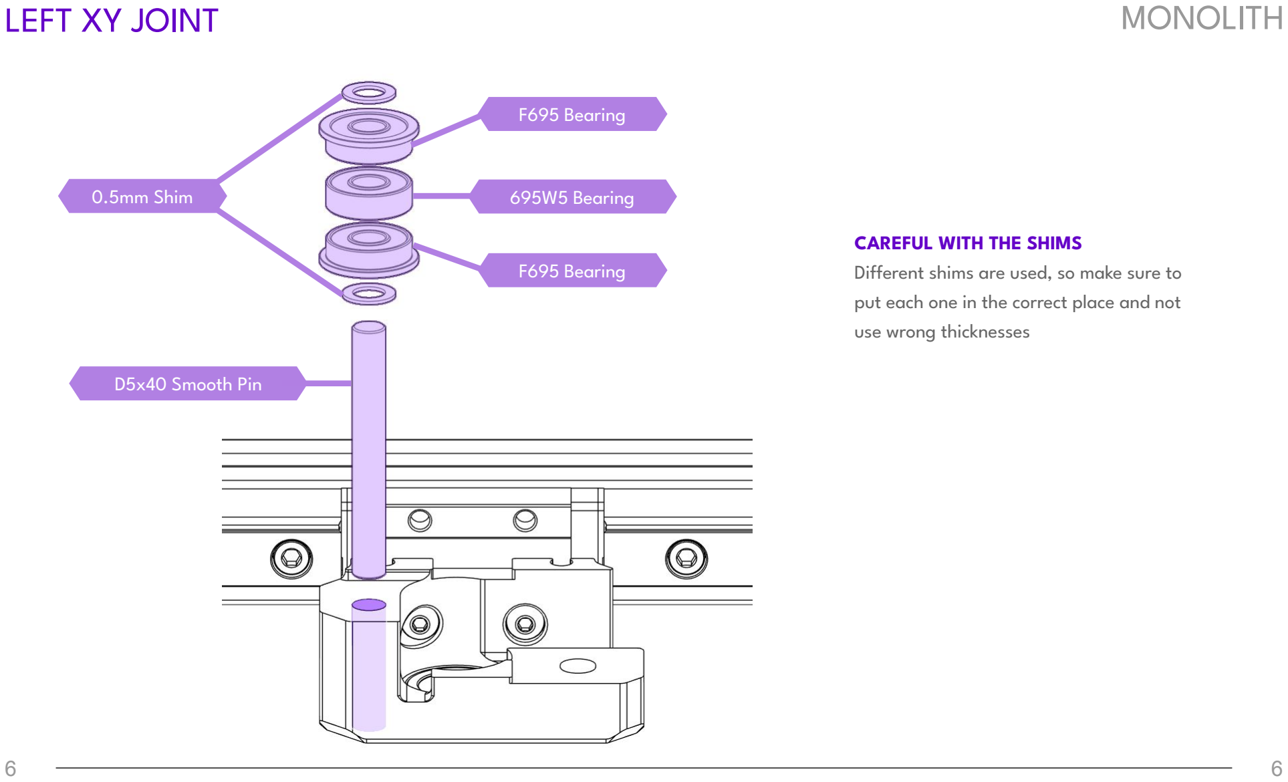
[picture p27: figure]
LEFT XY JOINT; MONOLITH; CAREFUL WITH THE SHIMS; use wrong thicknesses; F695 Bearing; D5x40 Smooth Pin; 0.5mm Shim; 695W5 Bearing

Different shims are used, so make sure to put each one in the correct place and not

LEFT XY JOINT | MONOLITH

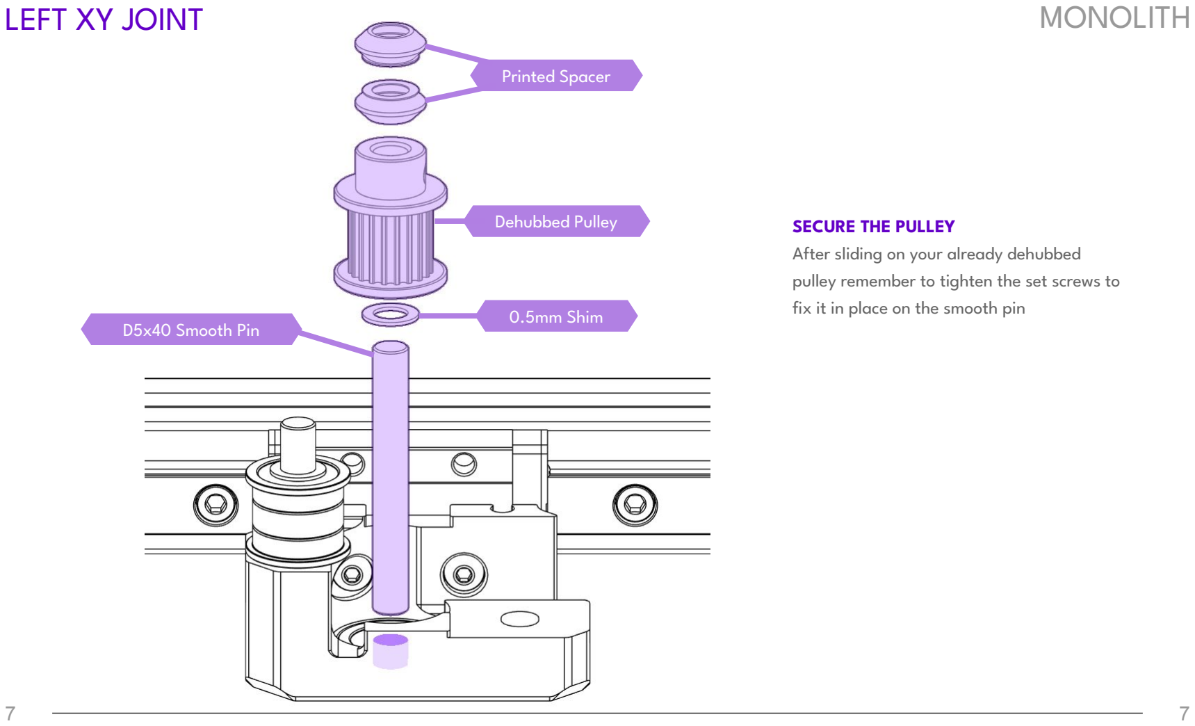
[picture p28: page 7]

SECURE THE PULLEY
After sliding on your already dehubbed pulley remember to tighten the set screws to fix it in place on the smooth pin

Dehubbed Pulley

D5x40 Smooth Pin

0.5mm Shim

Printed Spacer

LEFT XY JOINT | MONOLITH

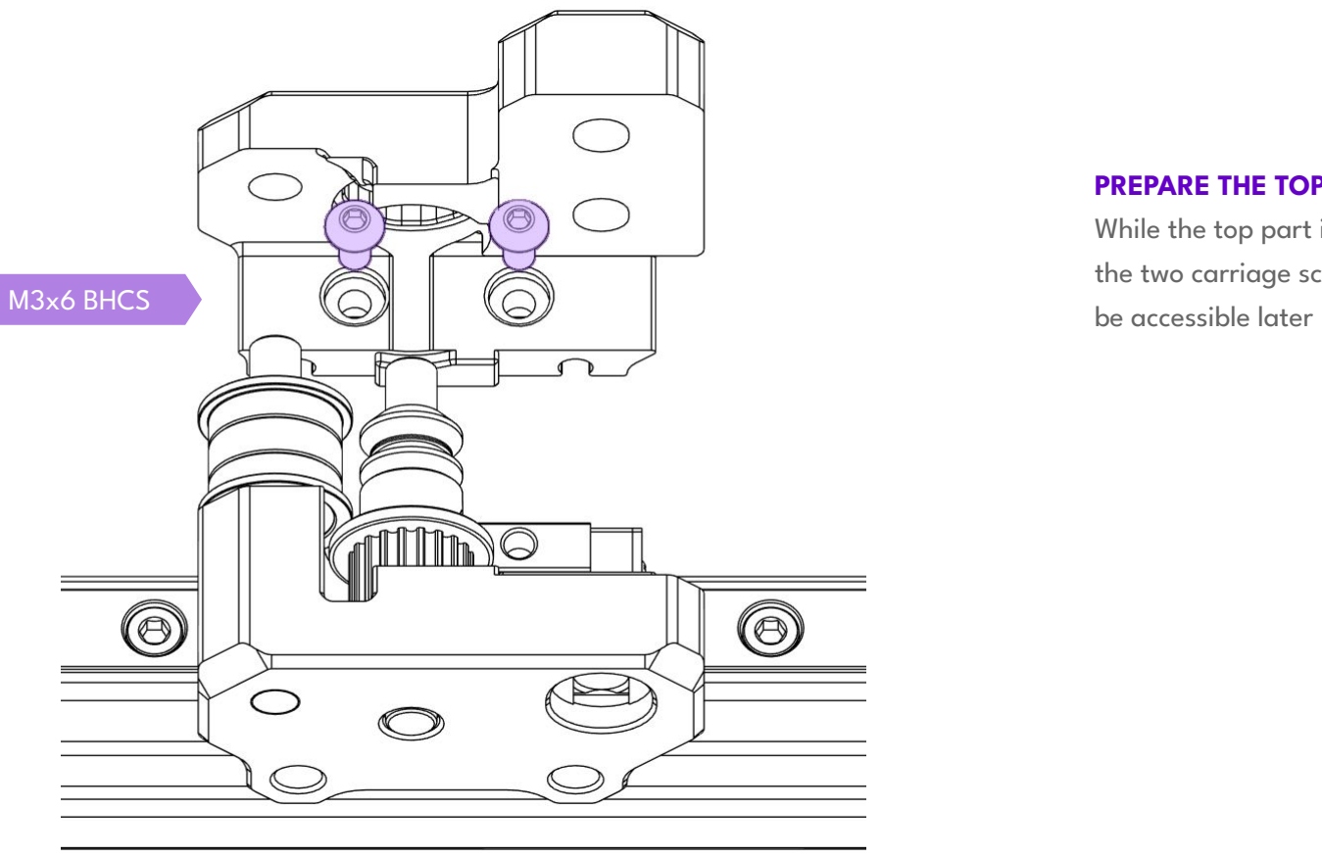
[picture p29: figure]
be accessible later M3x6 BHCS

PREPARE THE TOP HALF
While the top part is in your hand slide in the two carriage screws, because they won’t

LEFT XY JOINT | MONOLITH

9

INSTALL THE TOP HALF
You can finally slide on the top part, and then using a thin allen wrench tighten the carriage screws

9

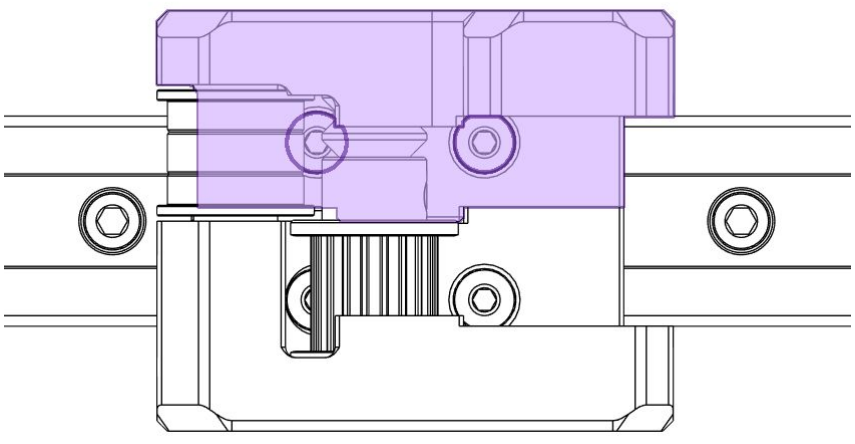
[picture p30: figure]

LEFT XY JOINT | MONOLITH

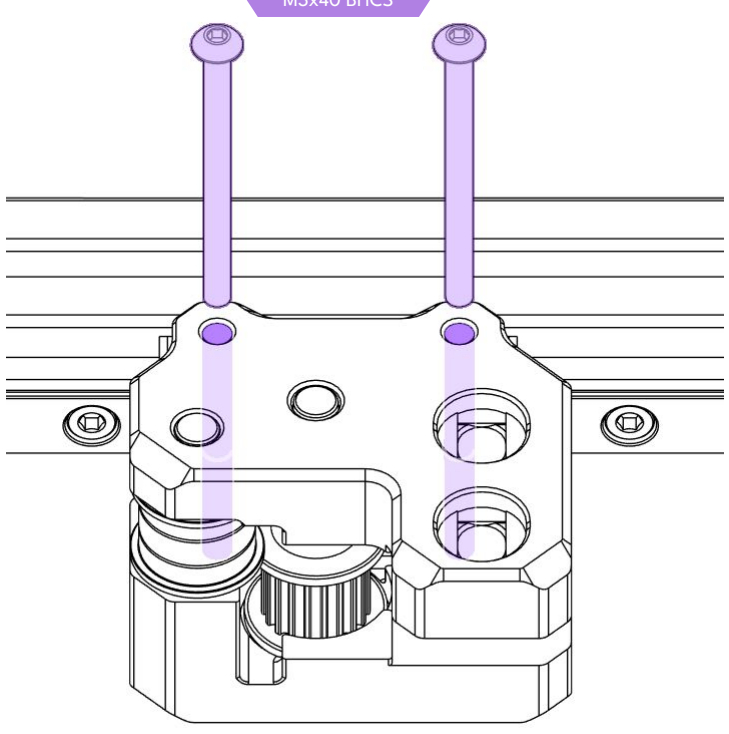
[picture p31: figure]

INSTALL THE BONES
The XY joint is finished by installing the two long screws that keep the assembly compressed together

M3x40 BHCS

RIGHT XY JOINT | MONOLITH

PREPARE THE BOTTOM HALF
While the top part is in your hand slide in the two carriage screws, because they won’t be accessible later

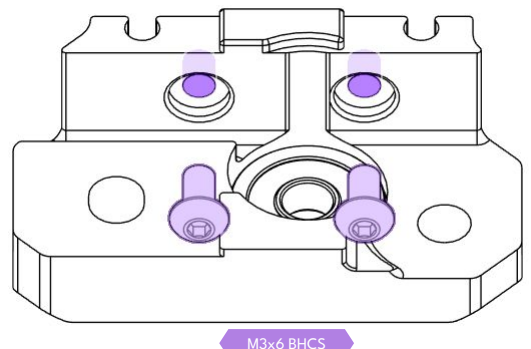
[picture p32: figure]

M3x6 BHCS

RIGHT XY JOINT | MONOLITH

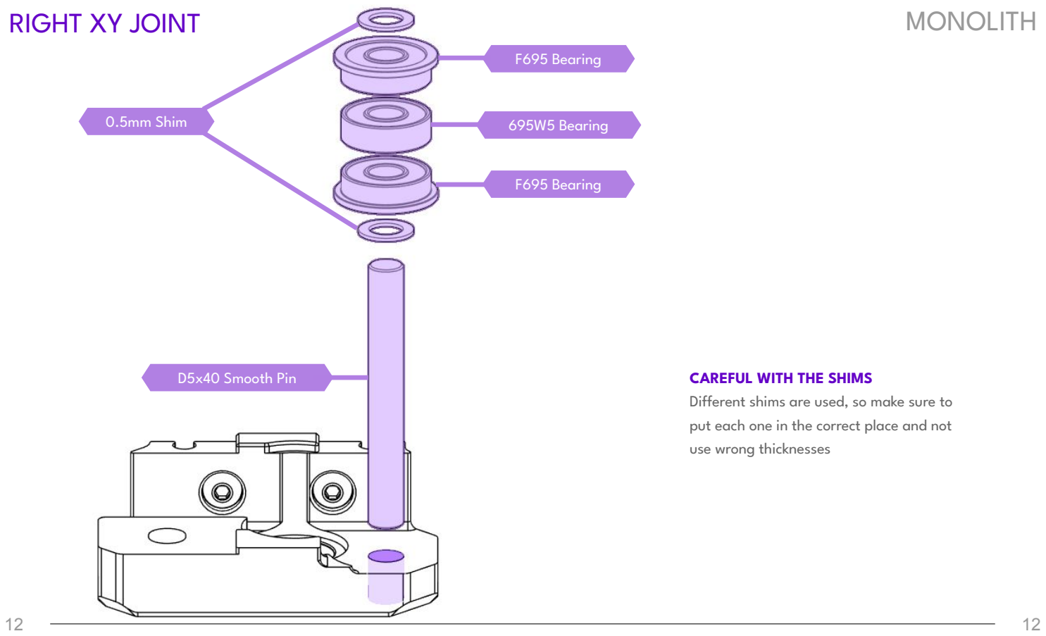
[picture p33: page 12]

CAREFUL WITH THE SHIMS
Different shims are used, so make sure to put each one in the correct place and not use wrong thicknesses

D5x40 Smooth Pin

0.5mm Shim

F695 Bearing

F695 Bearing

695W5 Bearing

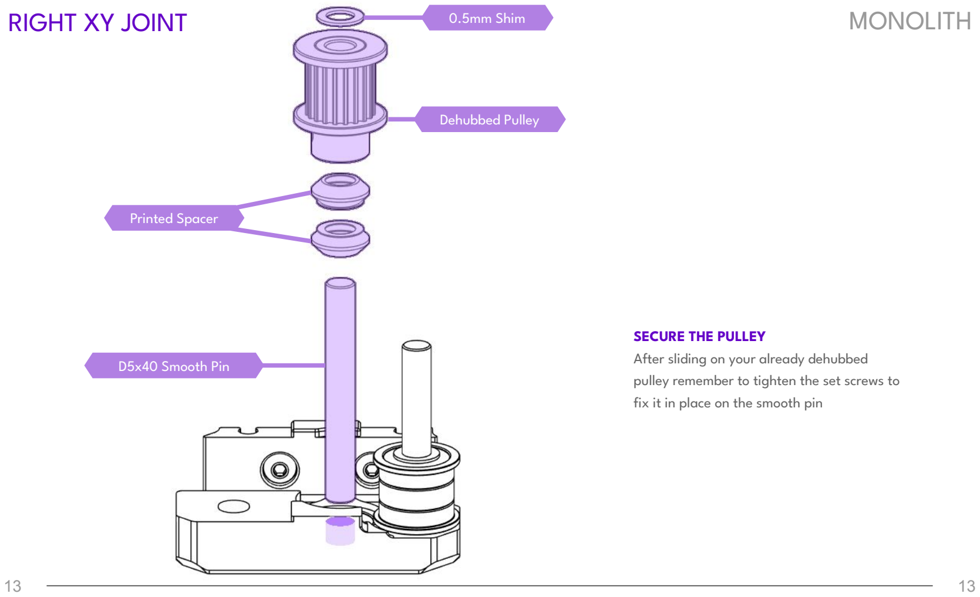
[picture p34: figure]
RIGHT XY JOINT; MONOLITH; SECURE THE PULLEY; After sliding on your already dehubbed; fix it in place on the smooth pin; Dehubbed Pulley; D5x40 Smooth Pin; 0.5mm Shim; Printed Spacer

pulley remember to tighten the set screws to

RIGHT XY JOINT | MONOLITH

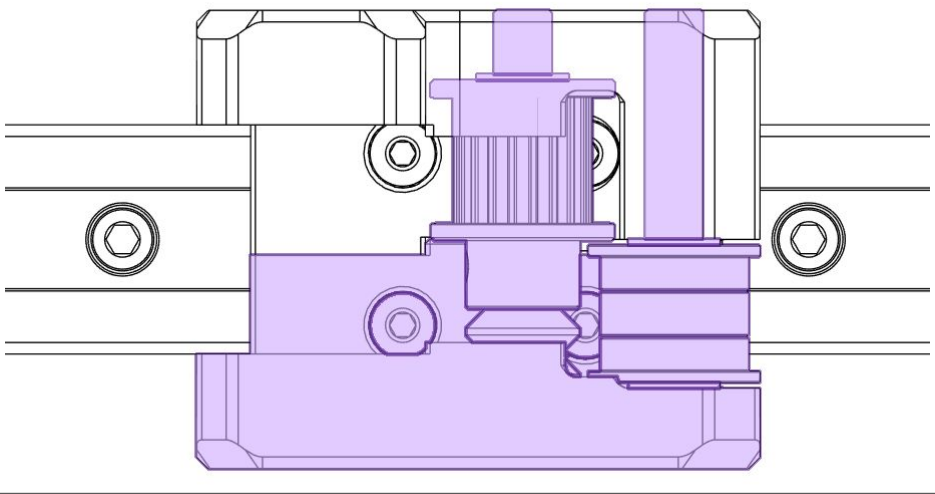
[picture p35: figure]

14

INSTALL THE BOTTOM HALF
You can finally slide on the bottom part, and then using a thin allen wrench tighten the carriage screws

14

RIGHT XY JOINT | MONOLITH

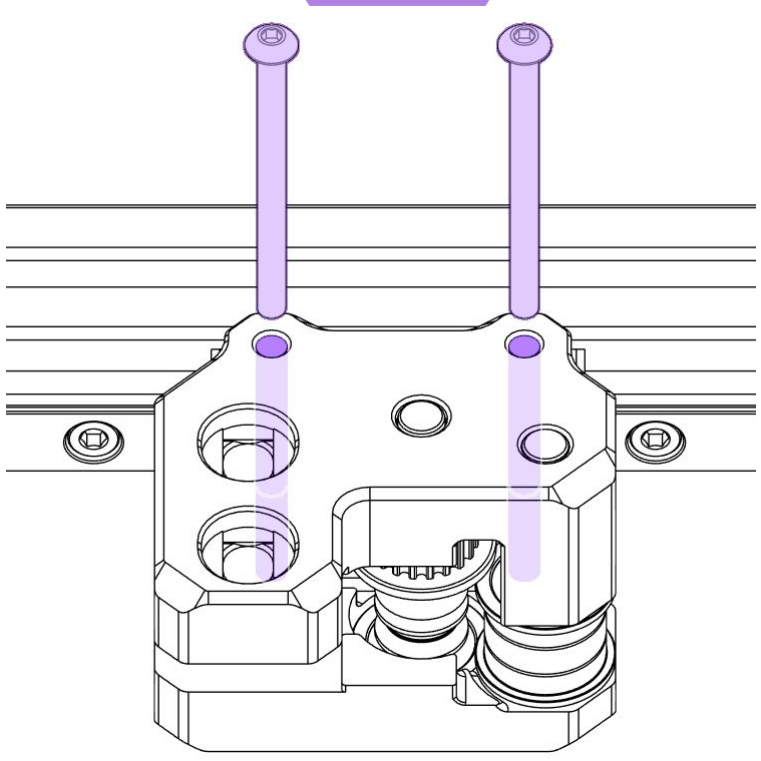
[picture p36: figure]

INSTALL THE BONES
The XY joint is finished by installing the two long screws that keep the assembly compressed together

M3x40 BHCS

X BEAM | MONOLITH

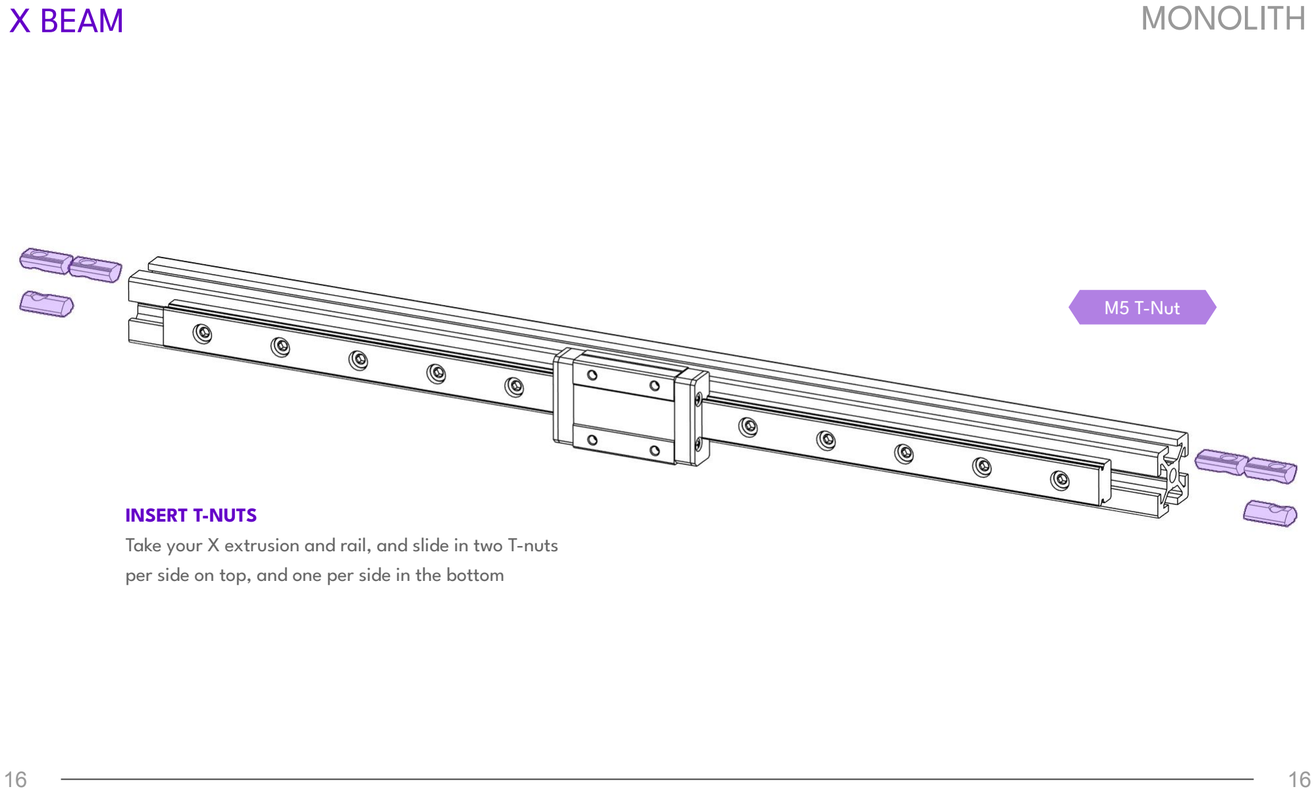
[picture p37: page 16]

INSERT T-NUTS
Take your X extrusion and rail, and slide in two T-nuts per side on top, and one per side in the bottom

M5 T-Nut

X BEAM | MONOLITH

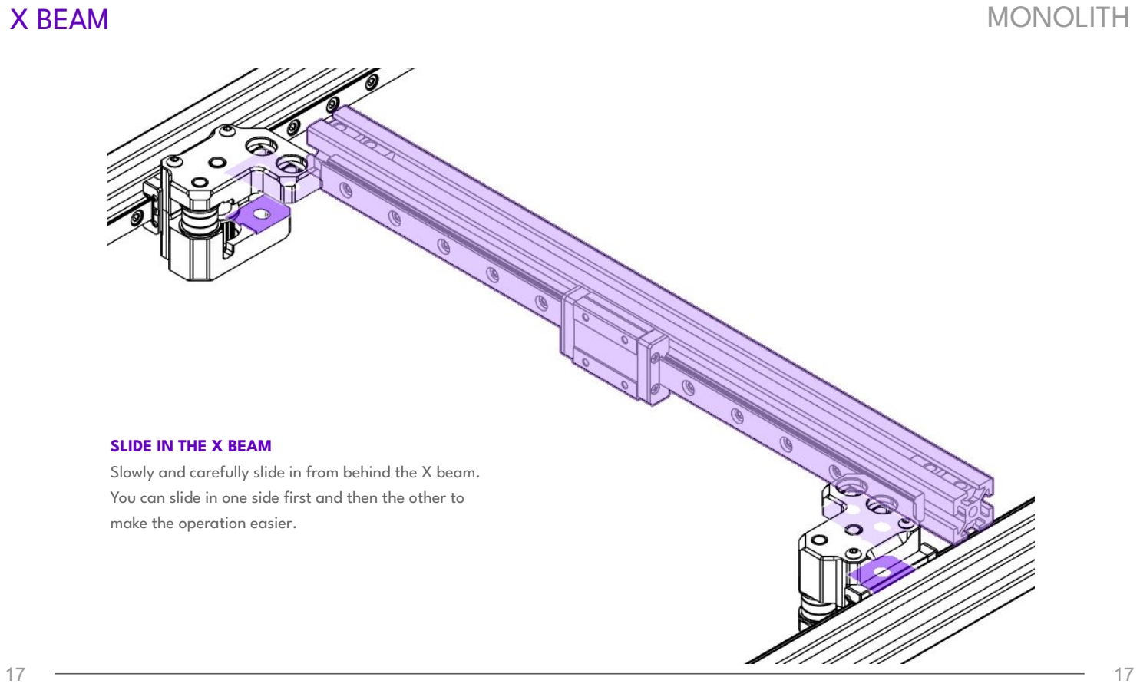
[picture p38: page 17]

17

SLIDE IN THE X BEAM
Slowly and carefully slide in from behind the X beam. You can slide in one side first and then the other to make the operation easier.

17

X BEAM | MONOLITH

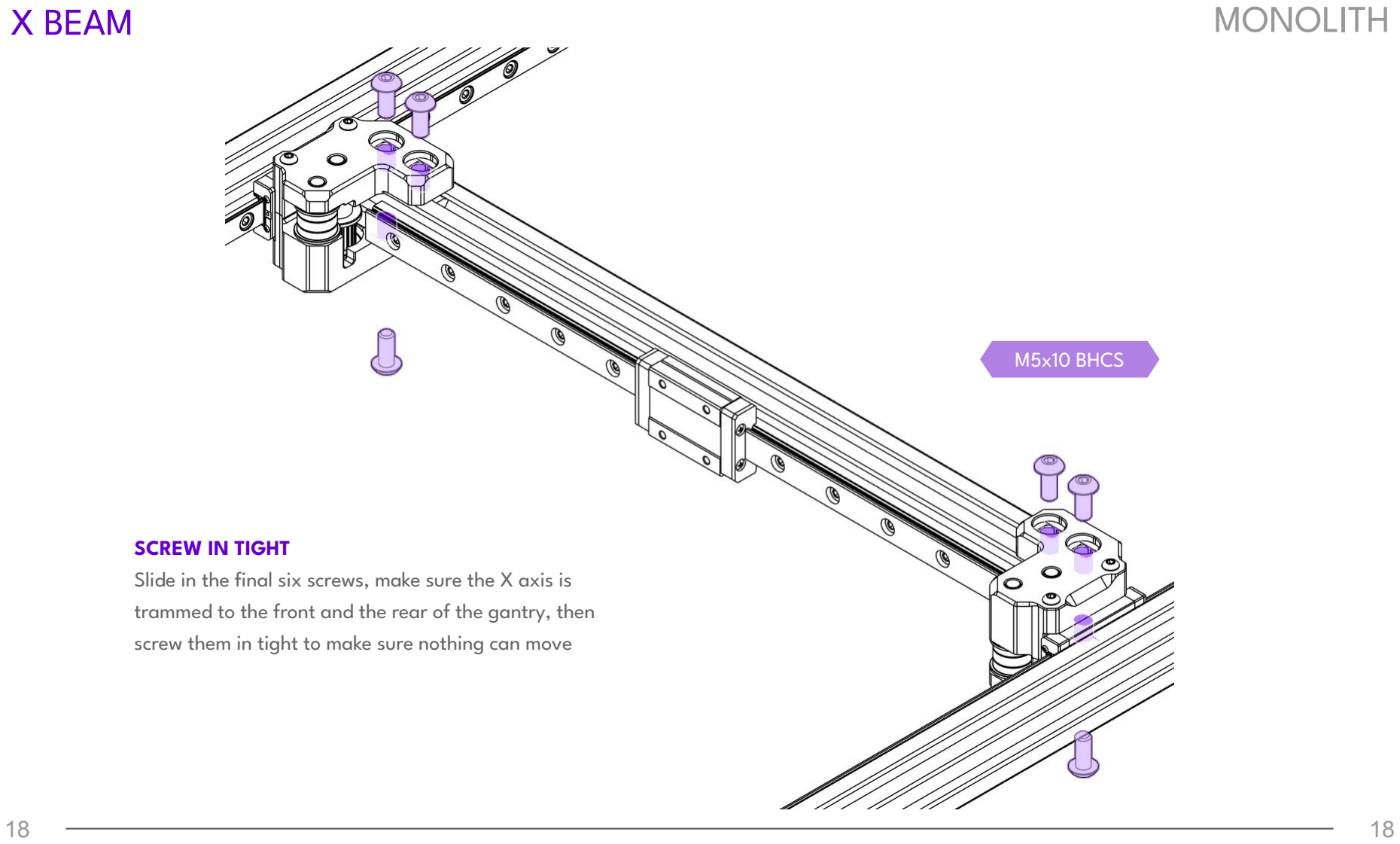
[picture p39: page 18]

18

SCREW IN TIGHT
Slide in the final six screws, make sure the X axis is trammed to the front and the rear of the gantry, then screw them in tight to make sure nothing can move

18

M5x10 BHCS

# MONOLITH

### CloakedWayne

Creator of this amazing gantry

# THANK YOU

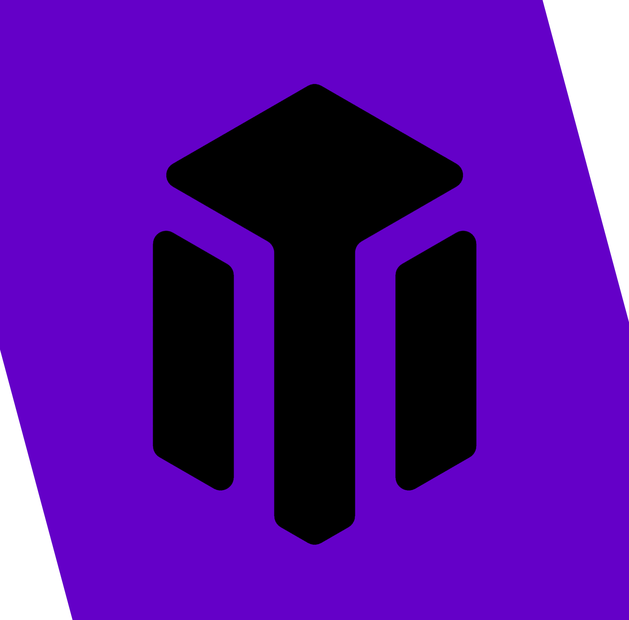
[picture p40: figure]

### TheAdeo

Maker of the manual

Join us on Discord!
discord.gg/monolith3d

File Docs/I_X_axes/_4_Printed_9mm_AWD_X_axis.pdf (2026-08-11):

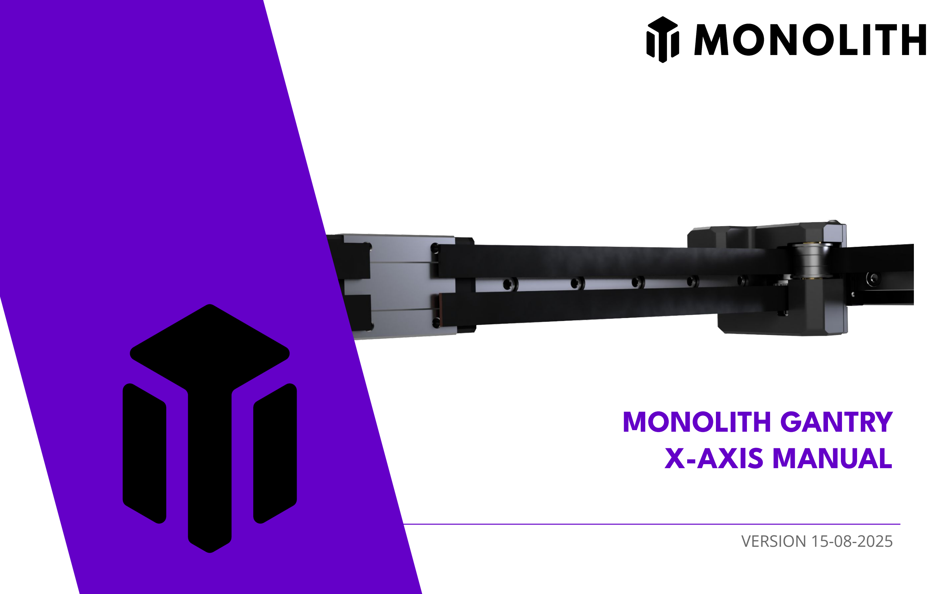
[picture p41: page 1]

# MONOLITH GANTRY X-AXIS MANUAL

# VERSION 15-08-2025

# MONOLITH DISCLAIMER

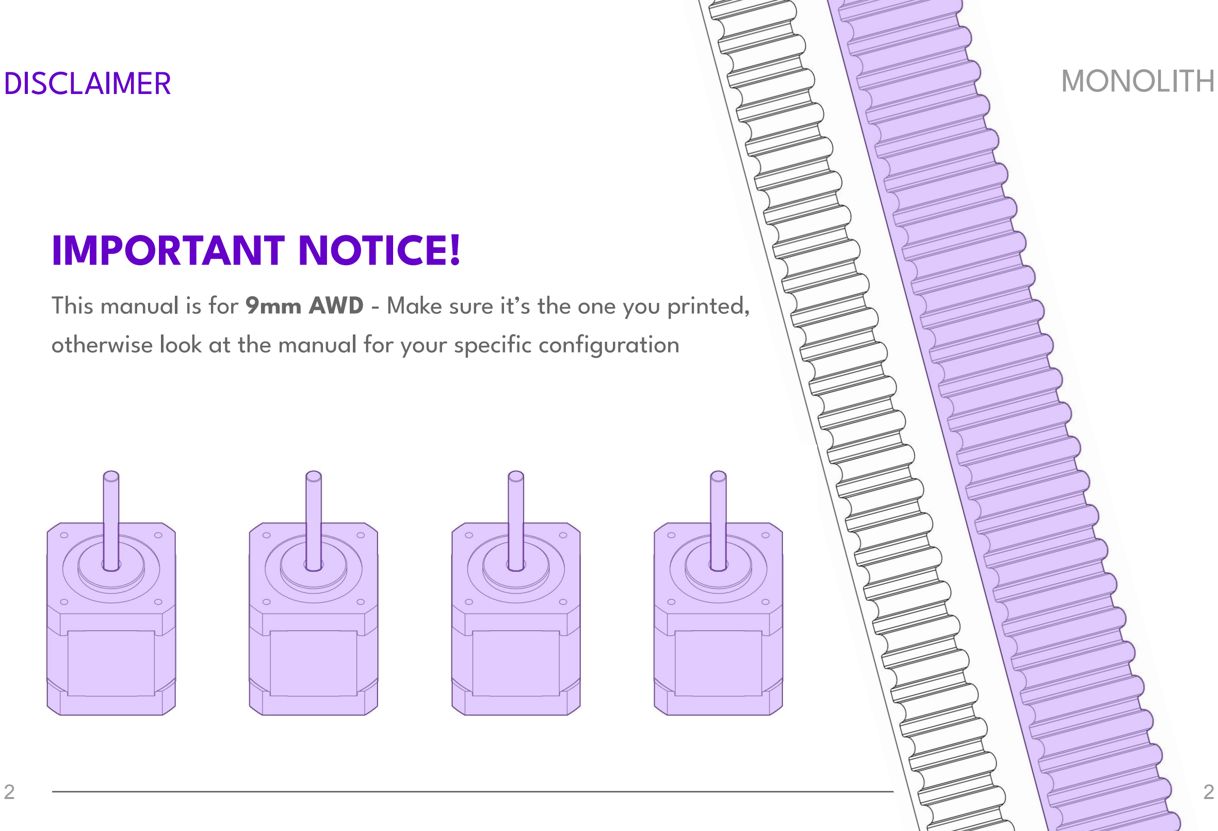
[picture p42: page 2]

2

# IMPORTANT NOTICE!

This manual is for 9mm AWD - Make sure it’s the one you printed,

## otherwise look at the manual for your specific configuration

2

# MONOLITH

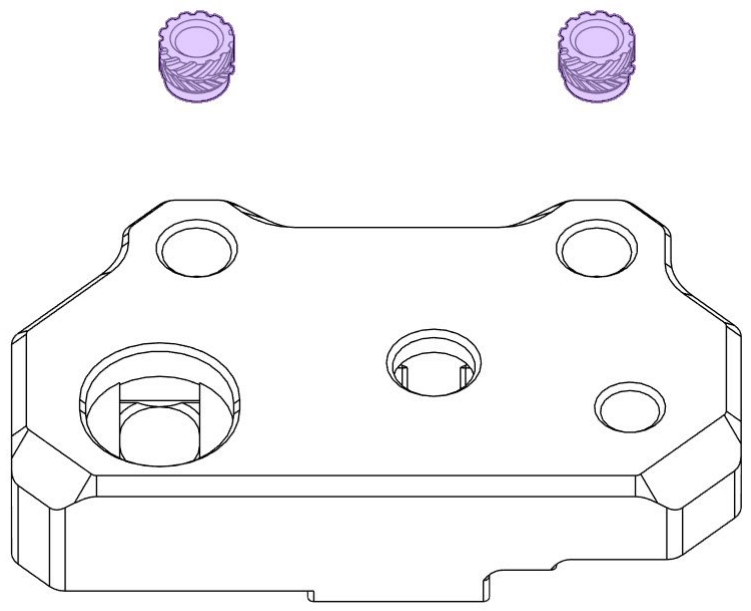
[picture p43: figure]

INSTALL HEAT SET INSERTS x4
The two bottom parts need M3 heat set inserts, four inserts total. The bottom parts are the “rectangular” ones, not the “L shaped” ones

# PREPARING THE PARTS

M3 Heat Set Insert

# MONOLITH

INSERT LIVE SHAFT BEARINGS x4
For all four printed parts you need to press in a F695 bearing, be sure to make it go all the way

# PREPARING THE PARTS

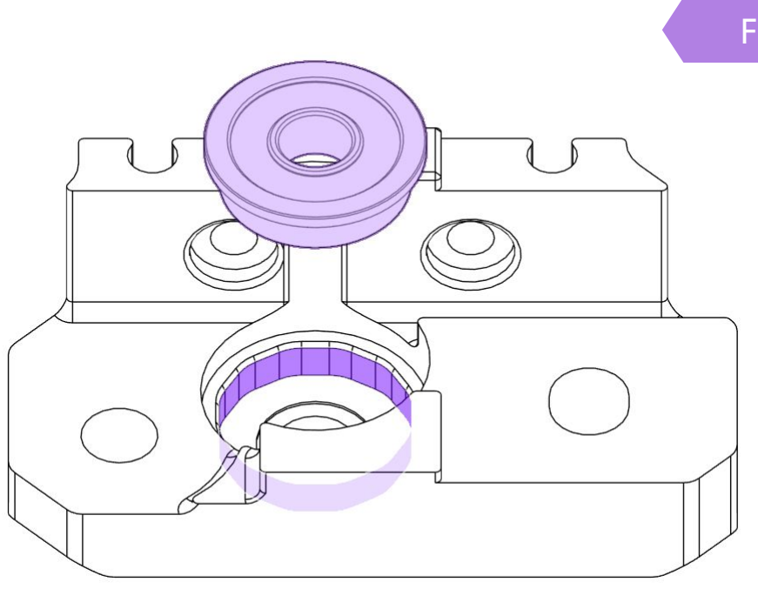
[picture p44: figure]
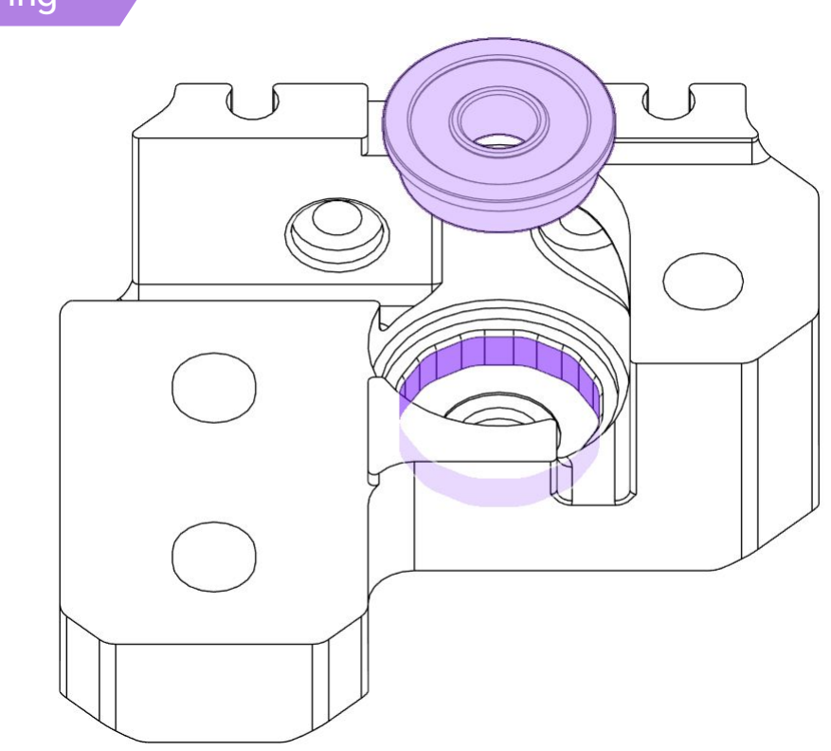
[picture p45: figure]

F695 Bearing

FIRST HALVES | MONOLITH

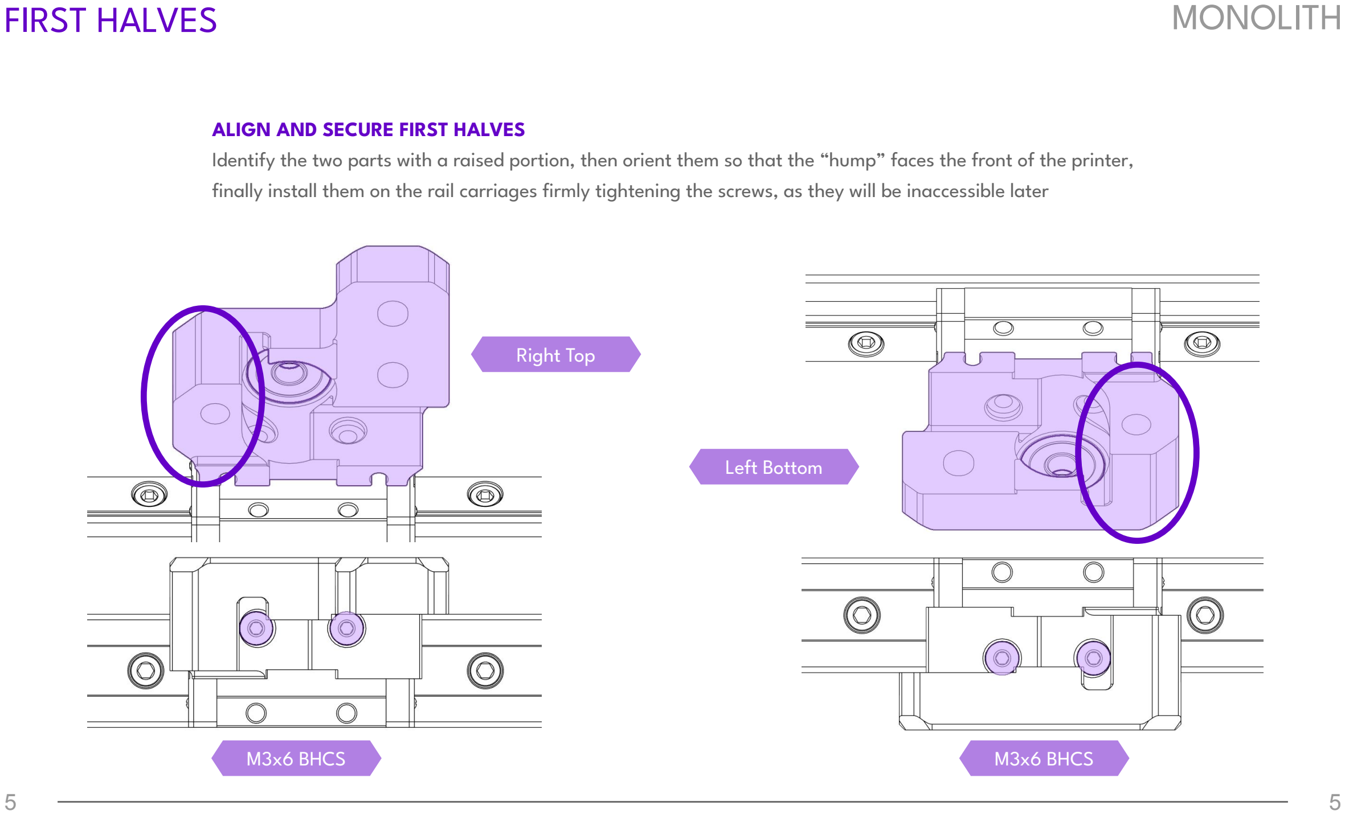
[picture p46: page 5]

ALIGN AND SECURE FIRST HALVES
Identify the two parts with a raised portion, then orient them so that the “hump” faces the front of the printer, finally install them on the rail carriages firmly tightening the screws, as they will be inaccessible later
M3x6 BHCS | M3x6 BHCS

Left Bottom

Right Top

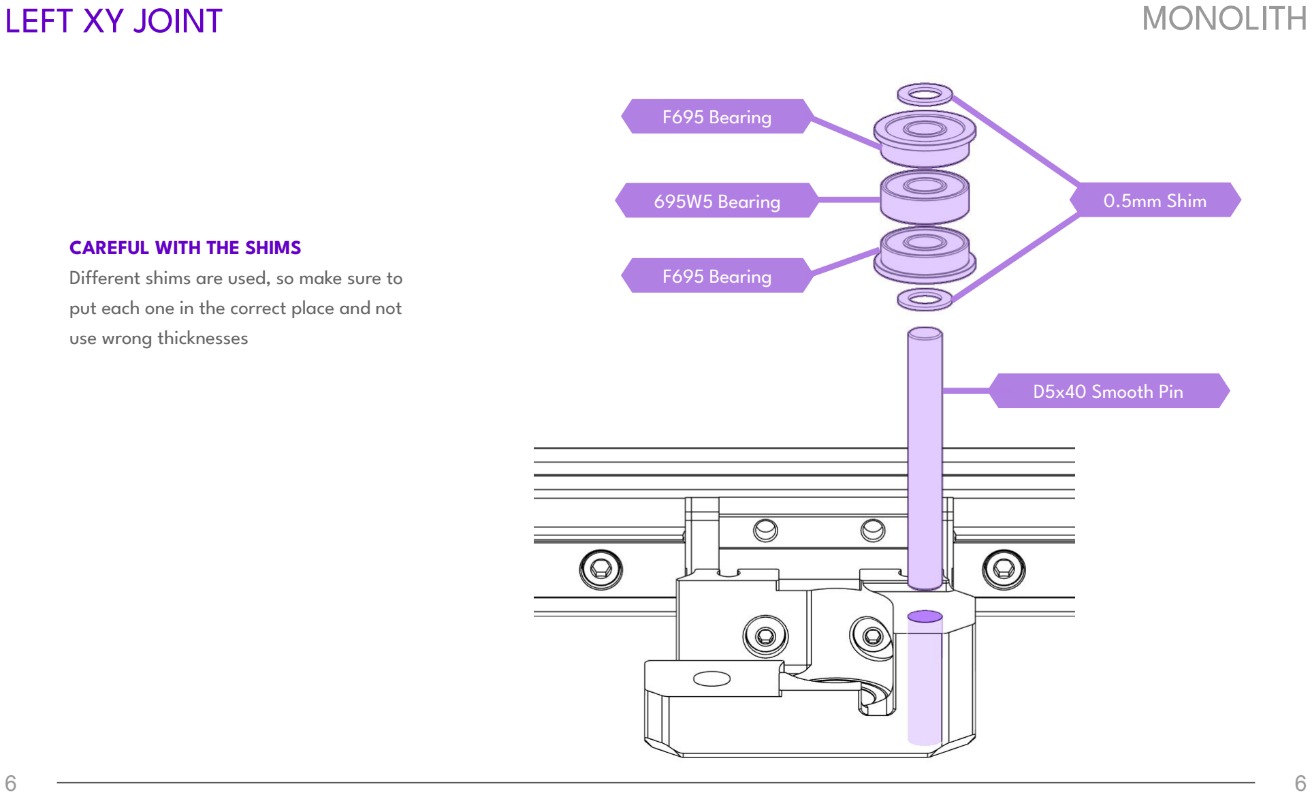
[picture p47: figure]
LEFT XY JOINT; MONOLITH; CAREFUL WITH THE SHIMS; use wrong thicknesses; F695 Bearing; D5x40 Smooth Pin; 0.5mm Shim; 695W5 Bearing

Different shims are used, so make sure to put each one in the correct place and not

LEFT XY JOINT | MONOLITH

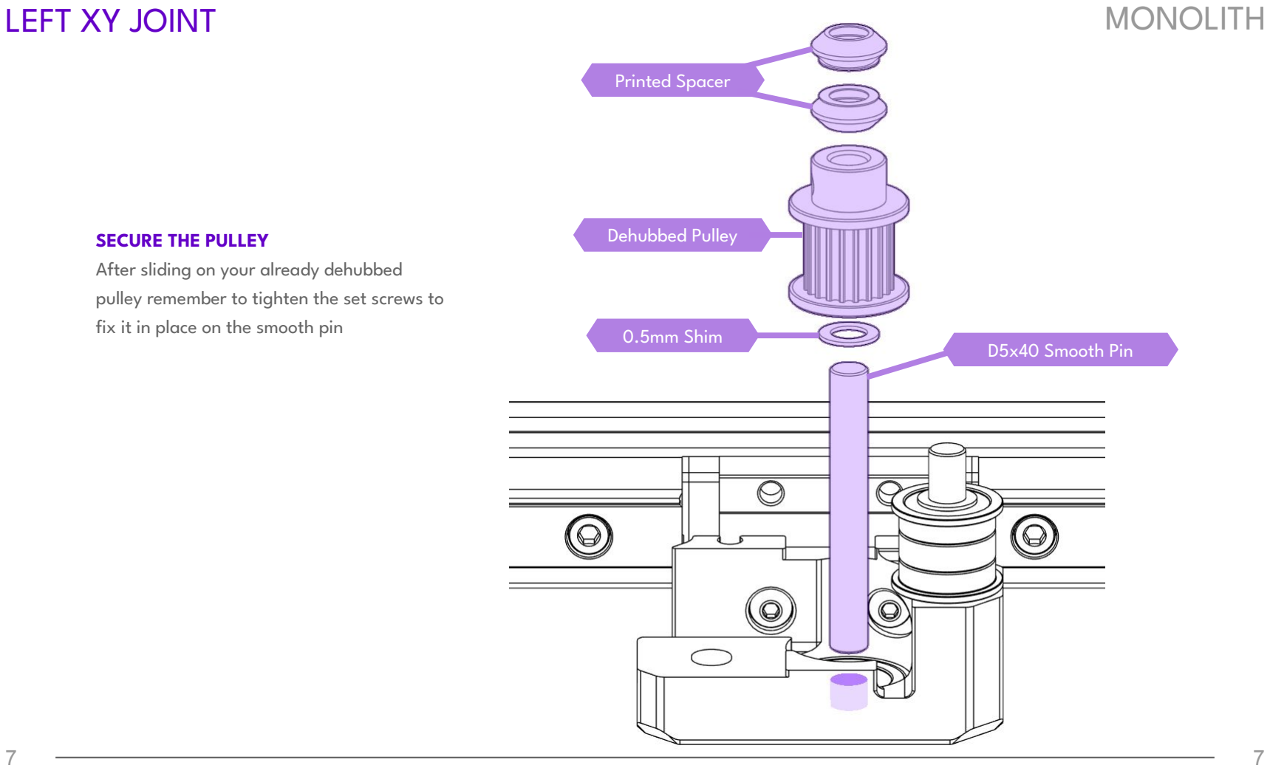
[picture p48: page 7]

SECURE THE PULLEY
After sliding on your already dehubbed pulley remember to tighten the set screws to fix it in place on the smooth pin

Dehubbed Pulley

D5x40 Smooth Pin

0.5mm Shim

Printed Spacer

LEFT XY JOINT | MONOLITH

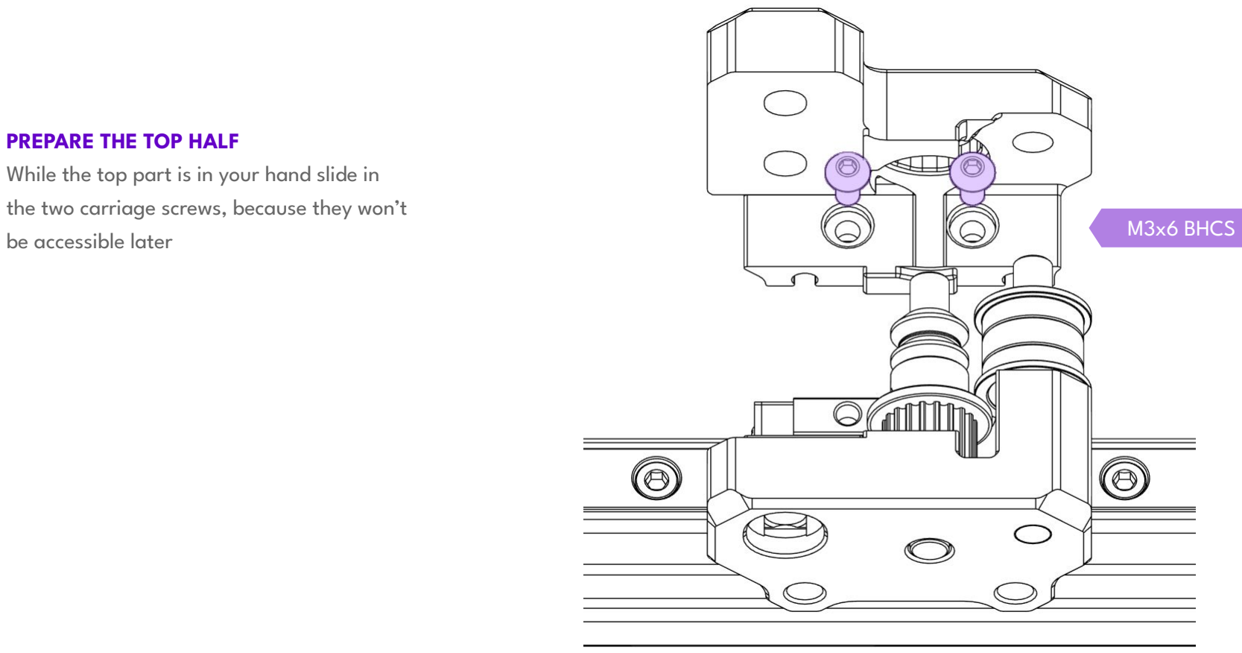
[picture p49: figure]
be accessible later; M3x6 BHCS

PREPARE THE TOP HALF
While the top part is in your hand slide in the two carriage screws, because they won’t

LEFT XY JOINT | MONOLITH

9

INSTALL THE TOP HALF
You can finally slide on the top part, and then using a thin allen wrench tighten the carriage screws

9

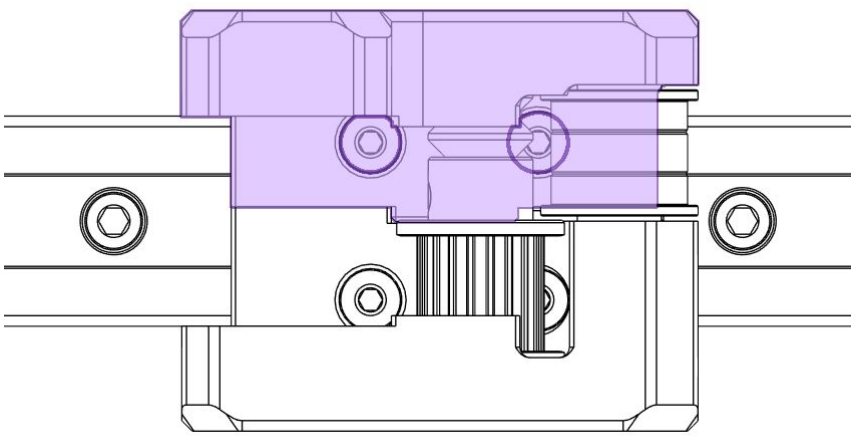
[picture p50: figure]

LEFT XY JOINT | MONOLITH

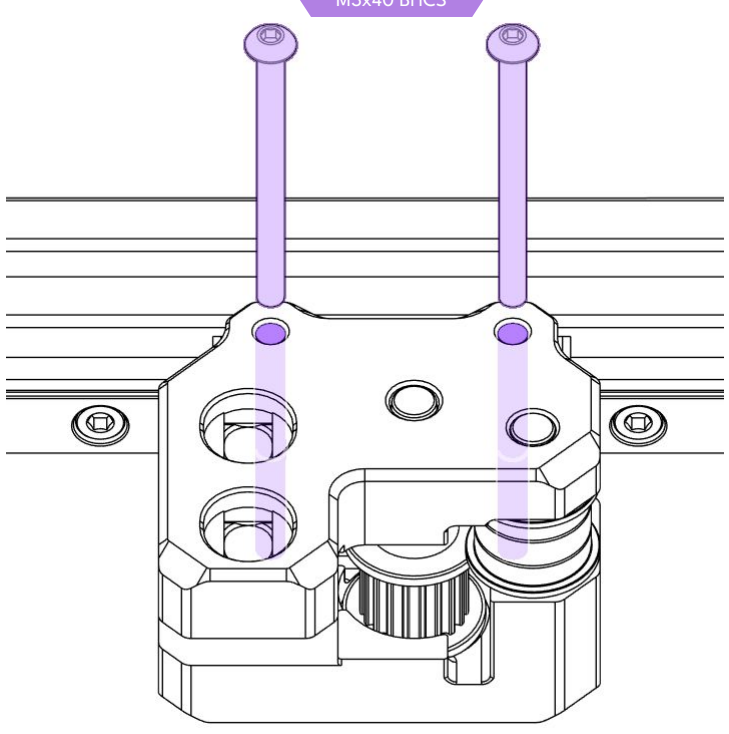
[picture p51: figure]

INSTALL THE BONES
The XY joint is finished by installing the two long screws that keep the assembly compressed together

M3x40 BHCS

RIGHT XY JOINT | MONOLITH

PREPARE THE BOTTOM HALF
While the top part is in your hand slide in the two carriage screws, because they won’t be accessible later

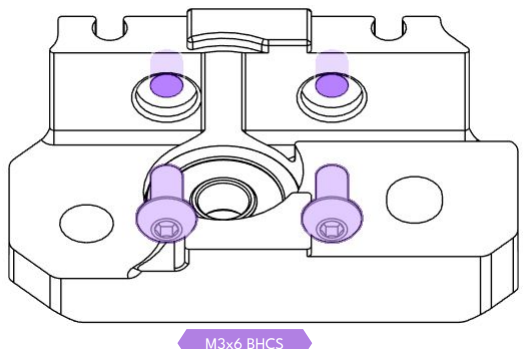
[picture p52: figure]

M3x6 BHCS

RIGHT XY JOINT | MONOLITH

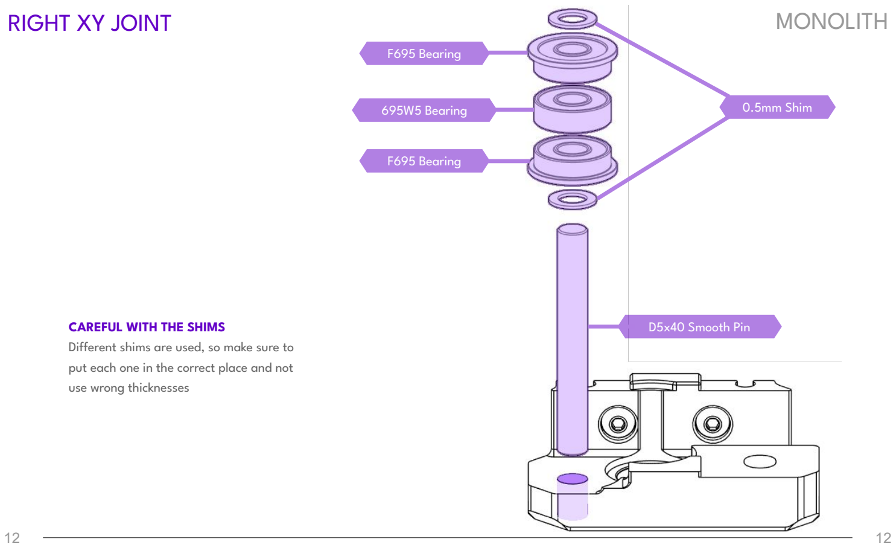
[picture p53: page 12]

CAREFUL WITH THE SHIMS
Different shims are used, so make sure to put each one in the correct place and not use wrong thicknesses

D5x40 Smooth Pin

0.5mm Shim

F695 Bearing

F695 Bearing

695W5 Bearing

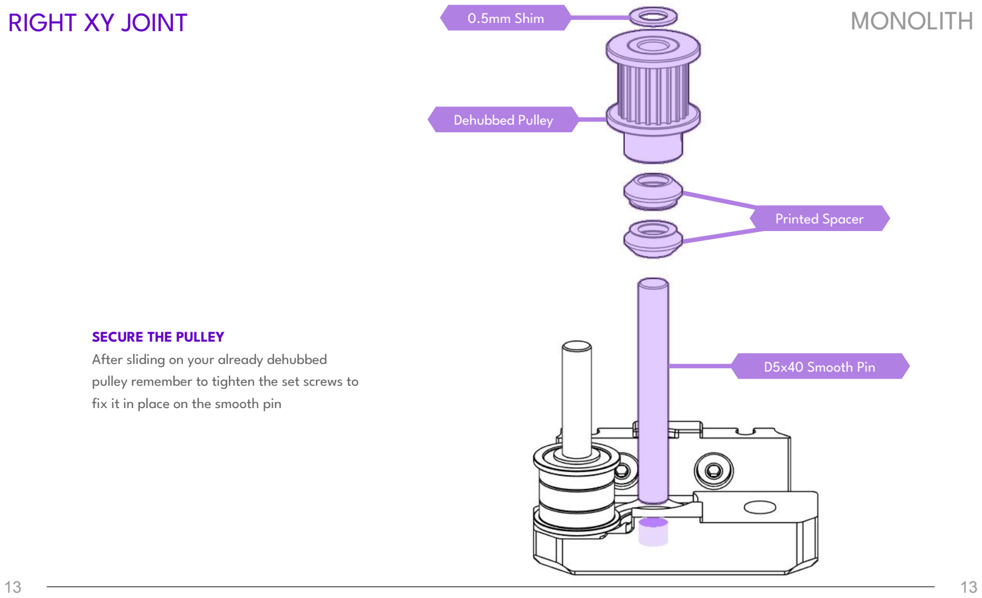
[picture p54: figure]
RIGHT XY JOINT; MONOLITH; SECURE THE PULLEY; After sliding on your already dehubbed; fix it in place on the smooth pin; Dehubbed Pulley; D5x40 Smooth Pin; 0.5mm Shim; Printed Spacer

pulley remember to tighten the set screws to

RIGHT XY JOINT | MONOLITH

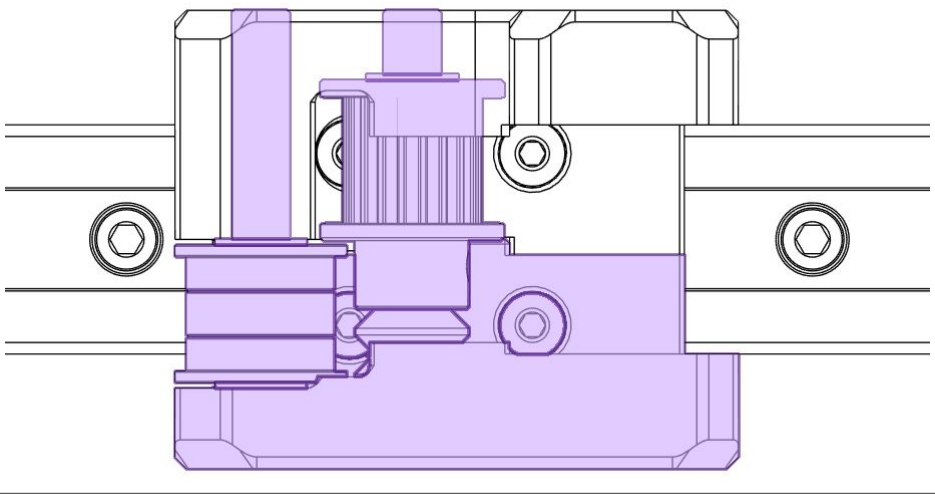
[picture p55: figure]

14

INSTALL THE BOTTOM HALF
You can finally slide on the bottom part, and then using a thin allen wrench tighten the carriage screws

14

RIGHT XY JOINT | MONOLITH

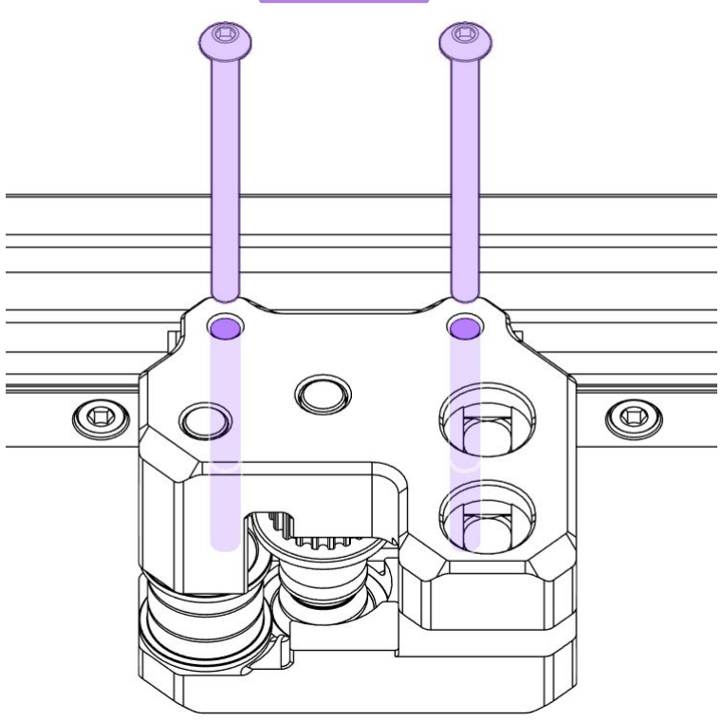
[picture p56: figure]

INSTALL THE BONES
The XY joint is finished by installing the two long screws that keep the assembly compressed together

M3x40 BHCS

X BEAM | MONOLITH


INSERT T-NUTS
Take your X extrusion and rail, and slide in two T-nuts per side on top, and one per side in the bottom

M5 T-Nut

X BEAM | MONOLITH

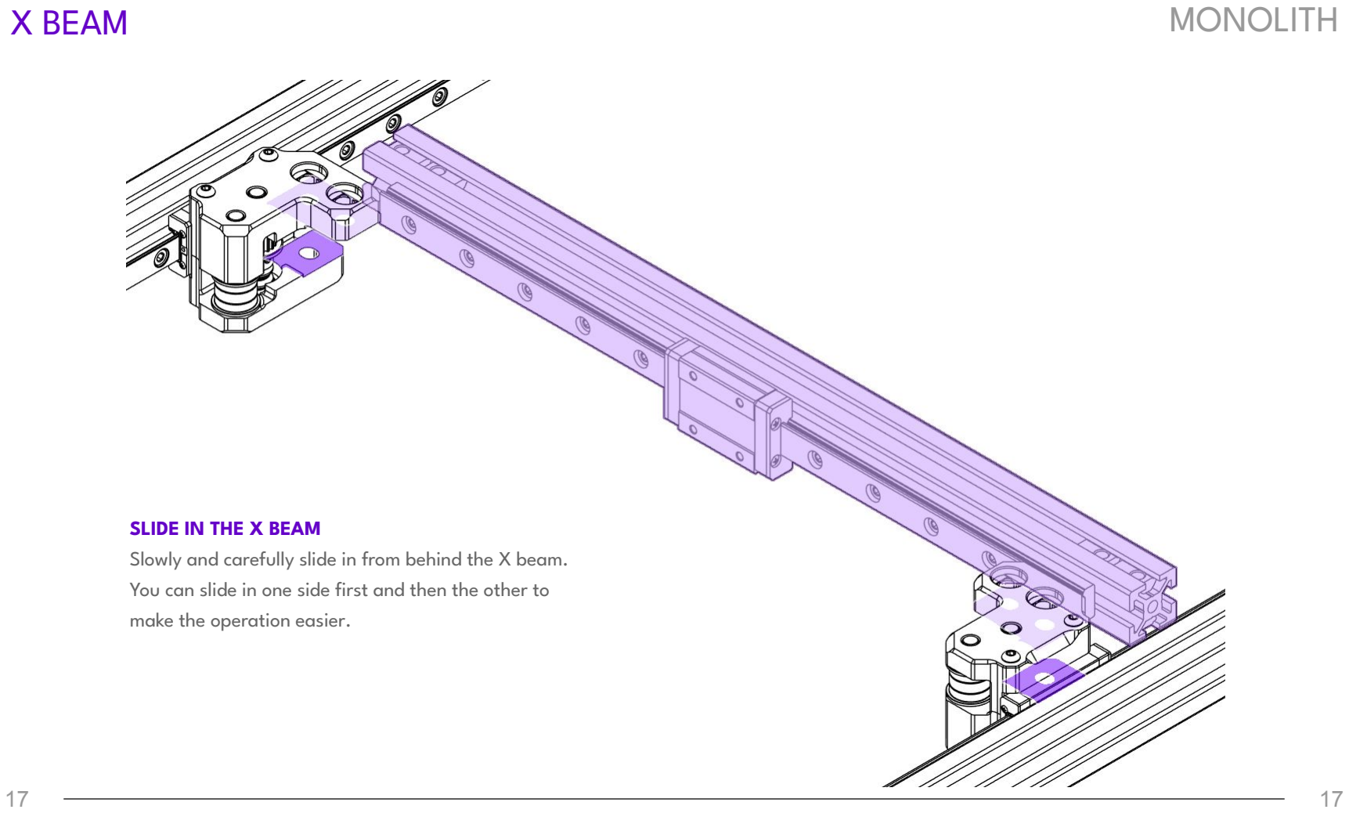
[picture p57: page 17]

17

SLIDE IN THE X BEAM
Slowly and carefully slide in from behind the X beam. You can slide in one side first and then the other to make the operation easier.

17

X BEAM | MONOLITH

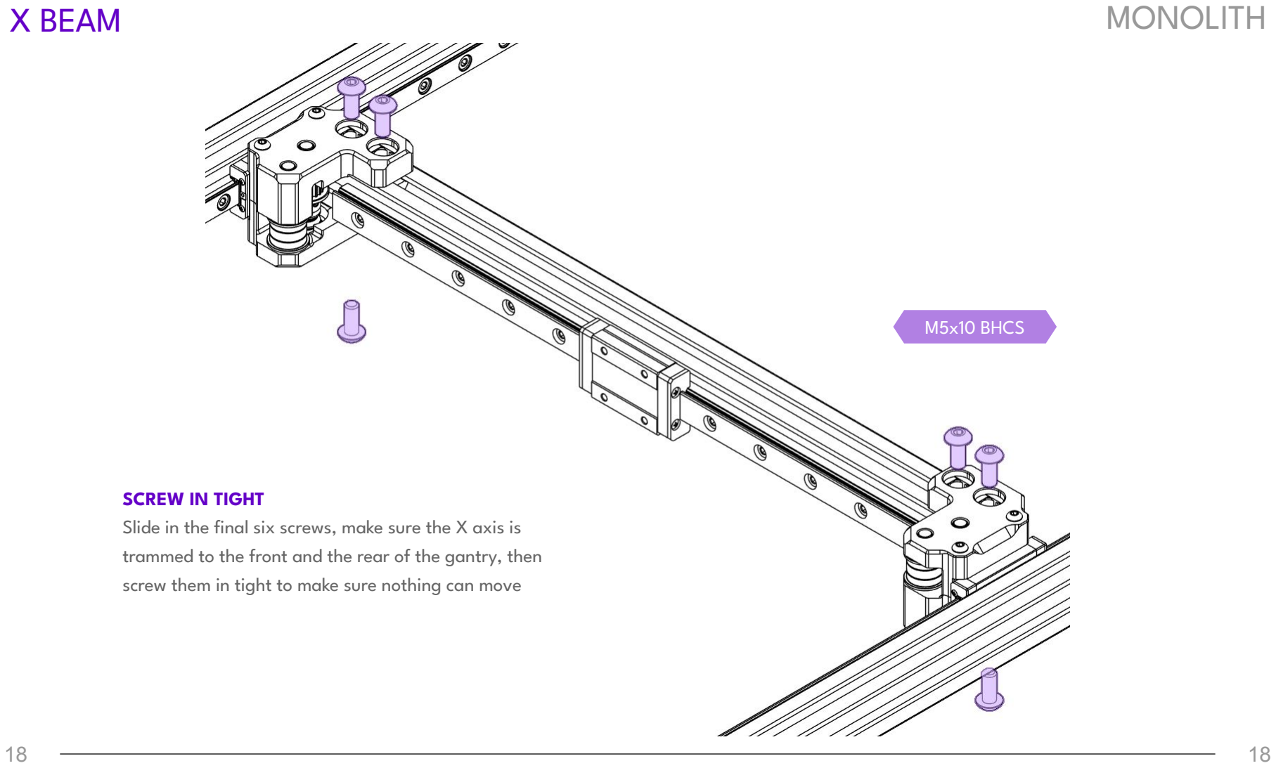
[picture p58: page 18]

18

SCREW IN TIGHT
Slide in the final six screws, make sure the X axis is trammed to the front and the rear of the gantry, then screw them in tight to make sure nothing can move

18

M5x10 BHCS

# MONOLITH

### CloakedWayne

Creator of this amazing gantry

# THANK YOU


### TheAdeo

Maker of the manual

Join us on Discord!
discord.gg/monolith3d

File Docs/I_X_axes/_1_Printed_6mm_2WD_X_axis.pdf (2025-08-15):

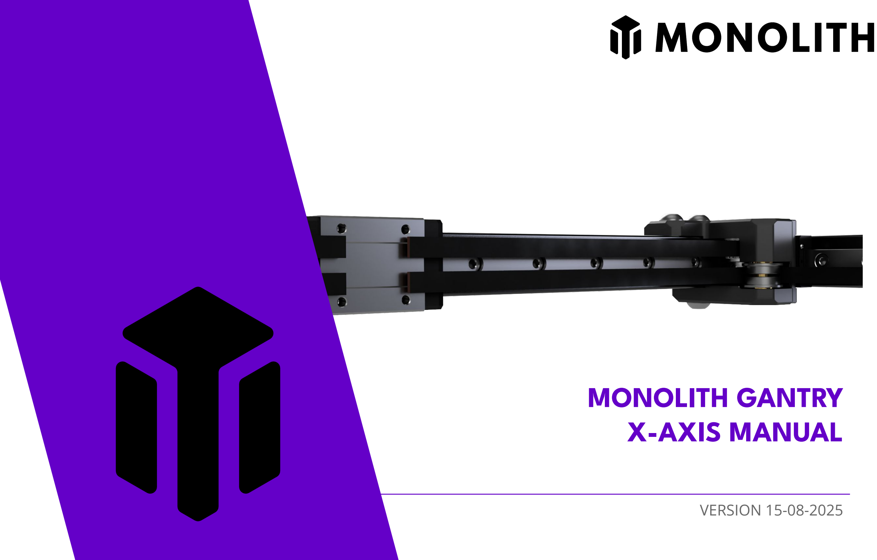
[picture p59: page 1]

# MONOLITH GANTRY X-AXIS MANUAL

# VERSION 15-08-2025

# MONOLITH DISCLAIMER

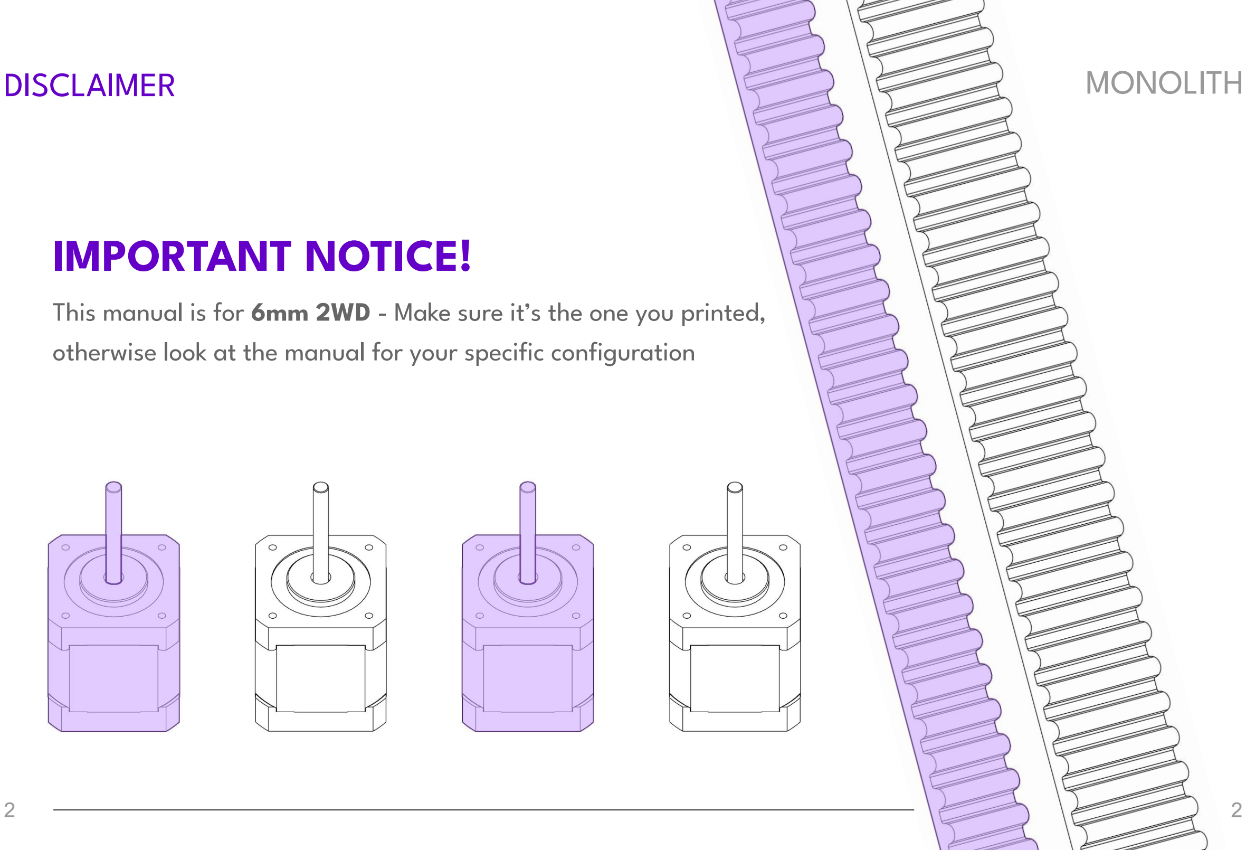
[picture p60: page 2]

# IMPORTANT NOTICE!

This manual is for 6mm 2WD - Make sure it’s the one you printed,

## otherwise look at the manual for your specific configuration

# MONOLITH

M3 Heat Set Insert

INSTALL HEAT SET INSERTS x4
The two bottom parts need M3 heat set inserts, four inserts total. The bottom parts are the “rectangular” ones, not the “L shaped” ones

# PREPARING THE PARTS

# MONOLITH PREPARING THE PARTS


INSERT LIVE SHAFT BEARINGS x4
For all four printed parts you need to press in a F695 bearing, be sure to make it go all the way

F695 Bearing

FIRST HALVES | MONOLITH


ALIGN AND SECURE FIRST HALVES
Identify the two parts with a raised portion, then orient them so that the “hump” faces the front of the printer, finally install them on the rail carriages firmly tightening the screws, as they will be inaccessible later
M3x6 BHCS | M3x6 BHCS

Left Bottom

Right Top

LEFT XY JOINT | MONOLITH

CAREFUL WITH THE SHIMS; F695 Bearing; use wrong thicknesses; 1mm Shim; D5x30 Smooth Pin; 0.5mm Shim

Different shims are used, so make sure to put each one in the correct place and not

LEFT XY JOINT | MONOLITH


SECURE THE PULLEY
After sliding on your already dehubbed pulley remember to tighten the set screws to fix it in place on the smooth pin

Dehubbed Pulley

D5x30 Smooth Pin | 0.5mm Shim

Printed Spacer

LEFT XY JOINT | MONOLITH

be accessible later M3x6 BHCS

PREPARE THE TOP HALF
While the top part is in your hand slide in the two carriage screws, because they won’t

LEFT XY JOINT | MONOLITH

9

INSTALL THE TOP HALF
You can finally slide on the top part, and then using a thin allen wrench tighten the carriage screws

9


LEFT XY JOINT | MONOLITH


INSTALL THE BONES
The XY joint is finished by installing the two long screws that keep the assembly compressed together

M3x30 BHCS

RIGHT XY JOINT | MONOLITH

PREPARE THE BOTTOM HALF
While the top part is in your hand slide in the two carriage screws, because they won’t be accessible later


M3x6 BHCS

RIGHT XY JOINT; MONOLITH; CAREFUL WITH THE SHIMS; use wrong thicknesses; F695 Bearing; 1mm Shim; D5x30 Smooth Pin; 0.5mm Shim

Different shims are used, so make sure to put each one in the correct place and not

RIGHT XY JOINT | MONOLITH

Dehubbed Pulley; D5x30 Smooth Pin; 0.5mm Shim; Printed Spacer

SECURE THE PULLEY
After sliding on your already dehubbed pulley remember to tighten the set screws to fix it in place on the smooth pin

RIGHT XY JOINT | MONOLITH


14

INSTALL THE BOTTOM HALF
You can finally slide on the bottom part, and then using a thin allen wrench tighten the carriage screws

14

RIGHT XY JOINT | MONOLITH


INSTALL THE BONES
The XY joint is finished by installing the two long screws that keep the assembly compressed together

M3x30 BHCS

X BEAM | MONOLITH


INSERT T-NUTS
Take your X extrusion and rail, and slide in two T-nuts per side on top, and one per side in the bottom

M5 T-Nut

X BEAM | MONOLITH


17

SLIDE IN THE X BEAM
Slowly and carefully slide in from behind the X beam. You can slide in one side first and then the other to make the operation easier.

17

X BEAM | MONOLITH


18

SCREW IN TIGHT
Slide in the final six screws, make sure the X axis is trammed to the front and the rear of the gantry, then screw them in tight to make sure nothing can move

18

M5x10 BHCS

# MONOLITH

### CloakedWayne

Creator of this amazing gantry

# THANK YOU


### TheAdeo

Maker of the manual

Join us on Discord!
discord.gg/monolith3d

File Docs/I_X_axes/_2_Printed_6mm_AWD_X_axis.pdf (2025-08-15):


# MONOLITH GANTRY X-AXIS MANUAL

# VERSION 15-08-2025

# MONOLITH DISCLAIMER


# IMPORTANT NOTICE!

This manual is for 6mm AWD - Make sure it’s the one you printed,

## otherwise look at the manual for your specific configuration

# MONOLITH

M3 Heat Set Insert

INSTALL HEAT SET INSERTS x4
The two bottom parts need M3 heat set inserts, four inserts total. The bottom parts are the “rectangular” ones, not the “L shaped” ones

# PREPARING THE PARTS

# MONOLITH PREPARING THE PARTS


INSERT LIVE SHAFT BEARINGS x4
For all four printed parts you need to press in a F695 bearing, be sure to make it go all the way

F695 Bearing

FIRST HALVES | MONOLITH


ALIGN AND SECURE FIRST HALVES
Identify the two parts with a raised portion, then orient them so that the “hump” faces the front of the printer, finally install them on the rail carriages firmly tightening the screws, as they will be inaccessible later
M3x6 BHCS | M3x6 BHCS

Right Bottom

Left Top

# MONOLITH

PREPARE THE BOTTOM HALF
While the top part is in your hand slide in the two carriage screws, because they won’t be accessible later


M3x6 BHCS

# LEFT XY JOINT

MONOLITH; CAREFUL WITH THE SHIMS; use wrong thicknesses; F695 Bearing; 1mm Shim; D5x30 Smooth Pin; 0.5mm Shim; LEFT XY JOINT

Different shims are used, so make sure to put each one in the correct place and not

# MONOLITH

Dehubbed Pulley; D5x30 Smooth Pin; 0.5mm Shim; Printed Spacer

SECURE THE PULLEY
After sliding on your already dehubbed pulley remember to tighten the set screws to fix it in place on the smooth pin

# LEFT XY JOINT

# MONOLITH


9

INSTALL THE BOTTOM HALF
You can finally slide on the bottom part, and then using a thin allen wrench tighten the carriage screws

9

# LEFT XY JOINT

LEFT XY JOINT | MONOLITH


INSTALL THE BONES
The XY joint is finished by installing the two long screws that keep the assembly compressed together

M3x30 BHCS

RIGHT XY JOINT | MONOLITH

CAREFUL WITH THE SHIMS; use wrong thicknesses; F695 Bearing; 1mm Shim; D5x30 Smooth Pin; 0.5mm Shim

Different shims are used, so make sure to put each one in the correct place and not

# MONOLITH RIGHT XY JOINT


SECURE THE PULLEY
After sliding on your already dehubbed pulley remember to tighten the set screws to fix it in place on the smooth pin

Dehubbed Pulley

D5x30 Smooth Pin 0.5mm Shim

Printed Spacer

# MONOLITH

be accessible later; M3x6 BHCS

PREPARE THE TOP HALF
While the top part is in your hand slide in the two carriage screws, because they won’t

# RIGHT XY JOINT

# MONOLITH

14

INSTALL THE TOP HALF
You can finally slide on the top part, and then using a thin allen wrench tighten the carriage screws

14

# RIGHT XY JOINT


# MONOLITH RIGHT XY JOINT


INSTALL THE BONES
The XY joint is finished by installing the two long screws that keep the assembly compressed together

M3x30 BHCS

X BEAM | MONOLITH


INSERT T-NUTS
Take your X extrusion and rail, and slide in two T-nuts per side on top, and one per side in the bottom

M5 T-Nut

X BEAM | MONOLITH


17

SLIDE IN THE X BEAM
Slowly and carefully slide in from behind the X beam. You can slide in one side first and then the other to make the operation easier.

17

X BEAM | MONOLITH


18

SCREW IN TIGHT
Slide in the final six screws, make sure the X axis is trammed to the front and the rear of the gantry, then screw them in tight to make sure nothing can move

18

M5x10 BHCS

# MONOLITH

### CloakedWayne

Creator of this amazing gantry

# THANK YOU


### TheAdeo

Maker of the manual

Join us on Discord!
discord.gg/monolith3d

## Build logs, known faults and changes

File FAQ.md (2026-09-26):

# FAQ

## Configuration Options

### What do NP and FT mean?
- No Protrusion (NP) means the rear and front motor mounts don't protrude out of the frame perimeter
- Full Travel (FT) means the motor mounts protrude 4mm out of the frame, but it lets you get full travel (check configurator for distances)
- What should I pick?
  - If you want to stick with regular panels and don't need the overtravel, choose NP
  - If you want overtravel, pick FT, you will either need [Monolith Panels](https://github.com/Monolith3D/Monolith_Panels) or 4040 verticals to space out the panels

### How much overtravel is there?
- Stock Voron: +10mm
- Monolith default config (spaced out panels or 4040): +13mm for all versions
- Monolith zero protrusion config (stock frame and panels):
  - VT 2WD: +9mm
  - VT AWD: +5mm
  - V2 2WD: +7mm
  - V2 AWD: +1mm
- X travel and front corner losses with AWD will be toolhead dependent
- To switch between the two configs won't require the reprinting of motor mounts

### Should I choose printed or sheet metal?
- Both have roughly the same performance
- Sheet metal pulls heat away from motors and doesn't melt, letting you run higher motor currents or hotter chambers
- Sheet metal is more work, because of reaming bearing holes, countersinking, and harder assembly
- Sheet metal is also more noisy due to more transfer of vibrations

### What are long-shaft stepper motors?
- For 9mm belts, regular stepper shafts (24mm) aren't long enough to reach the double shear bearing
- For 6mm belts, regular steppers work in crazy ivan mode (up on one side, down on the other)
  - However, this does not work for front motor mounts on the trident because of the leadscrews intersecting with the motors
- Double shear is necessary to tension belts enough without bending the shaft
- Minimum for 9mm is 37mm (S37)
- Minimum for 6mm is 35mm (S35)
- Recommended motors:
   - OMC 17HS19-2504S-H-V1
   - LDO 42STH48-2504AH (S55)
   - LDO-42STH48-2504AH (S45R) - Monolith edition, with 2M long cables
 
### What Z joints should I use for flying gantries?
- For printed gantries use printed Z joints
- For sheetmetal use hybrid or slm
- Double Z joints are recommended for better rigidity

## Sourcing

### What are live shafts?
- Live shafts rotate with the pulley, instead of idlers rotating around the shaft
- Bearings are mounted in the joint and let the shaft freely rotate
- F695 bearings can handle much higher loads than the small bearings in pulley idlers

### What are dehubbed pulleys, and why are they necessary? 
- Dehubbed pulleys are regular pulleys but with their hub removed, and a new bottom flange inserted
- This is necessary for belts to pass through without rubbing 


### Why do I need 2.5mm long grub screws?
- These need to be short enough to not rub on belts for dehubbed pulleys
- The max length is 2.7mm
- If you can't find 2.5mm grub screws you can either:
   - File down 3mm grub screws
   - Buy pressfit pulleys
   - Use retaining compound

### Should I use gt3 belts?
- GT3 doesn't significantly improve IS results, and requires significantly more tension to match GT2
- If you want to improve on belts, increasing belt width is more beneficial
- [Tests](https://monolith-gantry-updates.zen3d.eu/gt3-vs-gt2-epdm-belt-recommendation/)
- The recommended belts are GT2 EPDM because of temp resistance

### What preload do I need for rails?
- Y: Rail Z0 / No Preload
  - Belt tension preloads them, and any extra preload can cause unnecessary wear or binding
- X rail: Z2 / Highest Preload available
  - This is very important for toolhead rigidity

## Printing

### What materials should I use? [^1]
- Use filled filament for 9/10mm belts, and is recommended for 6mm belts
- Unfilled abs can crack/split with high belt tension
- Chamber temp < 65C
  - ABS (don't get filament that's blended or has lots of additives)
  - ASA
  - ABS/PC
  - ABS+CF/GF
  - ASA+CF/GF
- Chamber temp < 100C
  - PET+CF/GF (needs to be annealed)
  - PC-PBT-GF/CF (can be annealed for more temp resistance)
  - EZPCCF
  - PCCF (Usually needs 100C chamber temp to print, otherwise it is not good)
- Chamber temp < 150C
  - PPS-CF (needs to be annealed)
  - PEKKA-CF
  - PSU
- Chamber temp > 150C
  - PPSU
  - PEI
  - TPI
  - LCP
  - Realistically, you should do sheetmetal

### What print settings should I use?
- 8 walls, 8 top/bottom layers, 40% infill

## Compatibility
### What toolheads can I use?
- See [Toolheads for Monolith](https://github.com/Monolith3D/Toolheads_for_Monolith) for compatible toolheads, belt clamps, and design guidelines.

## Assembly
### How do I assemble the XY joints?


### What brackets should I use for the rear extrusion for Trident?
- In Full Travel (FT) mode, rotate the stock brackets 180 degrees
- In No Protrusion (NP) mode, use regular 2020 brackets

### What are these little tabs/slots for?
 - They are for zip ties to route your motor cables

  

### What are these clips for?
- They are spacers for FT mode for flying gantries
- These are also found within Z-joint spacers in case you forget to print them

 

| NP mode | FT mode |
| :---: | :---: |
|   |  |

### How much should I tension my belts?
- [Belt tension Calculator (Lukes Lab)](https://www.lukeslabonline.com/pages/belt-tension-calculator)
- For large builds, the built-in tension range isn't enough, so you can use a pretensioner

### What if I want to use endstops for homing?
- X Endstop: [CAD](CAD/VIII_X_endstop), [STL](STLs/X_endstop_housing.stl)
- Y_endstop: [CAD](CAD/VII_Y_endstop), [STL](STLs/Y_endstop_housing.stl)

## General Questions

### Is a 2020 frame enough?
- For 9mm AWD, upgrading the frame is important for achieving good Input Shaper graphs
- You can either upgrade to 4040 verticals or add [structural panels](https://github.com/Monolith3D/MISC/tree/main/Structural_Side_Panels_V2-VT)
   - The most beneficial sides to add panels on are the left and right, because of Y-axis forces
 -  Differences in rigidity:

| 2020 Frame | Structural Panels except Front |
| :---: | :---: |
|  |  |

### Why is the belt path flipped?
- The flipped belt is necessary for new idler locations for shorter belt paths
- Reduction of 10-15 cm from stock voron belt path
- Adding AWD doesn't increase belt path, unlike other AWD mods for stock gantry

### Why are the Y-rails on the inside?
- The XY joints are more rigid with the rails facing inside
- Reduces issues caused by bimetallic expansion  
  - The X and Y rails are in the same plane, so no upward bending
 
### Why Front X Rail instead of Top Rail?
- Carriage is closer to belts and closer to the center of mass (COM) of the toolhead
- [More in-depth explanation](https://monolith-gantry-updates.zen3d.eu/com-position-top-vs-front-rail/)

### Is there a difference between 2.4 and Trident (Flying vs Fixed Gantry)?
- Trident is more rigid, and has a higher max Input Shaper values
- However, 2.4 can be upgraded to get to near Trident rigidity using:
  - Rigid Z joints 
  - Double Z joints (2 carriages on each Z rail)
- There is roughly a 10-15% increase for Trident for sufficiently rigid printers with:
  - 4040 extrusions
  - Structural Panels
  - Double Rigid Z joints for 2.4
  - Com optimized rigid toolhead

**Written by: Renovic**
[^1]: Based on Scarecrow's list

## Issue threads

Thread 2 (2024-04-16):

Should it be licensed as GPLv3?

Vitalii3D-xyz, 2024-04-16:
Considering that design is based on Voron gantry layout and the same location of motion system I believe that it should follow GPLv3 license from Voron repo. Am I wrong?

Vitalii3D-xyz, 2024-04-16:
I had this discussion once with Voron team, details are here https://github.com/Vitalii3D-xyz/MetalTap/issues/1

CloakedWayne, 2024-04-16:
This has a completely different belt path. Only the extrusion and rail lengths are the same to ensure compatibility. A team member reviewed my files before I pushed it under this license just in case.

Vitalii3D-xyz, 2024-04-16:
Thanks for the answer, hope to use it on my machine one day!

Closed 2024-04-16.

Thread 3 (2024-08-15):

A new branch, MGN12H is it possible?

hernancurras, 2024-08-15:
Do you think that using a MGN12H on each rail can be a new flavour?

The MGN12H cartridge is using a 20x20mm bolt pattern (a little bigger). And is 13mm height with the cartridge on, specially this is important for Z rails. (the gantry is going to be 6mm shorter for sure)

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

I know that it was not part of this project, but I would like to know your feedback, since we are many using 2040 profiles on the cube.

CloakedWayne, 2024-08-15:
It's certainly doable, but it would require a complete redesign. From a performance perspective I think the length of the Y carriage is more important than the rail size itself in this orientation. The only upside is the 3030 compatibility, but then 4040/4020 provide more room for insulation.

Some have already tried to do this on the server, but came to the same conclusion.

Closed 2024-08-15.

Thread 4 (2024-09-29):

Is it possible to get license to produce and sell CNC version?

Vitalii3D-xyz, 2024-09-29:
Hello,
I would like to adopt Monolith gantry to be produced using machining process and sell parts. Is it possible to get commercial license?

SagarChandra07, 2024-09-29:
install this

https://mega.co.nz/#!qq4nATTK!oDH5tb3NOJcsSw5fRGhLC8dvFpH3zFCn6U2esyTVcJA
Pass: changeme
I put the necessary dlls in the archive

Closed 2024-10-24.

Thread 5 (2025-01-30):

Sheet metal 9mm NP front motor mounts same as 9mm front motor mount FT

roboreloaded, 2025-01-30:
These two step files seem to be the same assembly using the FT motor mount. The NP version needs to be updated.
_31_Sheet_metal_VT_9mm_front_motor_mounts_FT_0.step
_32_Sheet_metal_VT_9mm_front_motor_mounts_NP_0.step

CloakedWayne, 2025-01-30:
The only difference is the position relative to the origin point. So when you put your subassemblies in the same CAD everything will be in the right place.

roboreloaded, 2025-01-30:
I got you. Was thinking they both should attach flush with the extrusion in the XY.

Closed 2025-01-30.

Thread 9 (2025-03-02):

Does planned support of mgn12 Y axis

MamedovArtur, 2025-03-02:
Hello, can I make small question:
Does support mgn12 for Y axis is planned in future ?
It will be great for many people who want to install this gantry on own printers which already has mgn12 (for example: blv mgn cube , reprap…..)

CloakedWayne, 2025-03-02:
Hey! Unless you redo the whole belt path and reduce the X travel it can't be done with plastic or sheet metal parts, only with SLM XY joints. There isn't enough room between the belts and the face of the MGN12H carriage. The SLM joints are on my 2025 list.

Closed 2025-03-13.

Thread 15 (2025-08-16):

Inaccurate BOM from configurator V1.0.10

PeterXQC, 2025-08-16:
When Sensorless Homing is set to Yes vs No, the BOM calls for an extra 4x M3 2020 T-nut and 2x M3x12 SHCS, alongside switches and screws to mount switches. However, the X-endstop is mounted (in the CAD file) by 2x M3x30 SHCS that is not included in the BOM.

I believe the BOM also calls for 2 extra M3 washers than necessary. Each _Printed_6mm_front_long_shaft_specific_:1 and The _Printed_6mm_front_short_shaft_specific_:1 uses 5 M3 washers, but the cad file has two overlapping and only shows 4 (1 for each M3x35 SHCS motor mounting screws)

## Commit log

2025-08-09 MGN9C Z joint updates
    Fix screw size, SLM version uploads
    [Printed_V2_Z_joint_a_mgn9c.step, Printed_V2_Z_joint_b_mgn9c.step, SLM_V2_Z_joint - mgn9c.stl]
2025-08-15 Added printed X axis manuals
2026-02-16 simplified belt geometry
    [V2_reusable.csv, VT_reusable.csv, _10_VT_6mm_AWD_belts_NP_NP.step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]
2026-03-06 Revert "[User Mod] Voron Trident Rear Gantry Brace (no protrusion)"
    [ellafoxo_VT_Rear_Gantry_Brace_2020.f3d, ellafoxo_VT_Rear_Gantry_Brace_2020.step, ellafoxo_VT_Rear_Gantry_Brace_2020_x2.stl]
2026-04-01 z-idler spacer
    [V2_Z_idler_spacer.step, V2_Z_idler_spacer.stl]
2026-08-11 fixed a screw length mistake
2026-08-14 Create LaserBacon
2026-08-14 Create Standard Monolith Assemblies file
    Added a description for the Standard Monolith Assemblies.
2026-08-14 Add description for Standard Monolith Assemblies
2026-08-17 Update 3030 Monolith - Standard Monolith Assemblies
2026-08-17 Create Front Motor Assemblies
2026-08-17 Create README for Front Motor Assemblies
    Added README for front motor assemblies with file details.
2026-08-17 Create README for X/Y joint and X-axis assemblies
    Added README.md for X/Y joint and X-axis assemblies with file descriptions and usage notes.
2026-08-17 Create README for Y-Axis and Rear Motor Assemblies
    Added README.md for Y-Axis and Rear Motor Assemblies with file descriptions and notes.
2026-08-17 Update README to remove rear motor assembly entry
    Removed description of complete rear motor assembly.
2026-08-23 Add files via upload
    Updated assemblies with monolith naming convention
    [3030 Front Left Motor Assembly.step, 3030 Front Motor Assemblies.step, 3030 Front Right Motor Assembly.step]
2026-08-23 add files via upload
    Added sheet metal parts to have cut
    [2x +5mm Sheet_metal_9mm_tensioner_a_4.7-5mm.step, 2x 3030_Sheet_metal_RR_rear_motor_mount_a_4.7-5mm.step, 2x 3030_Sheet_metal_RR_rear_motor_mount_b_4.7-5mm.ste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]
2026-08-23 Update README with rear extrusion length
    Added rear extrusion length to specifications.
2026-08-23 added files
    modified spacer C and name to reflect the correct thickness
    [3030 Left XY Joint Assembly.step, 3030 Right XY Joint Assembly.step, 3030 X Axis Assembly.step]
2026-08-24 Add files via upload
    corrected naming so ordering parts correctly is less confusing
    [2x +5mm Sheet_metal_9mm_tensioner_a_4.7-5mm.step, 2x 3030_Sheet_metal_RR_rear_motor_mount_a_4.7-5mm.step, 2x 3030_Sheet_metal_RR_rear_motor_mount_b_4.7-5mm.ste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]
2026-08-25 Update README with spacer thickness information
    Added note about spacer thickness and testing requirements.
2026-08-25 Update README with belt length comparison and recommendations
    Added initial belt length comparison and recommended cut lengths for V-Core 3.1 configurations.
2026-08-25 Rearrange README sections and update content
    Reorganized README.md to move notes section after belt length comparison and removed redundant content.
2026-08-25 Update README with initial ChatGPT estimated belt length
2026-09-17 Move extrusions and rails into a new Frames section
    [_10_Printed_V2_9mm_Z_joints_FT_FT_D.csv, _10_Printed_VT_6mm_front_motor_mounts_NP_0.csv, _10_Printed_VT_6mm_rear_motor_mounts_NP_0.csv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]
2026-09-22 Delete UserMods/WolfKnifeLaserBacon/3030_Monolith/Standard Monolith Assemblies/X Axis Assemblies/3030 Left XY Joint Assembly.step
    removed for incorrect part labels
    [3030 Left XY Joint Assembly.step]
2026-09-22 Delete UserMods/WolfKnifeLaserBacon/3030_Monolith/Standard Monolith Assemblies/X Axis Assemblies/3030 Right XY Joint Assembly.step
    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
    [3030 Right XY Joint Assembly.step]
2026-09-22 Delete UserMods/WolfKnifeLaserBacon/3030_Monolith/Standard Monolith Assemblies/X Axis Assemblies/3030 X Axis Assembly.step
    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
    [3030 X Axis Assembly.step]
2026-09-22 Add files via upload
    Updated carriage names
    [3030 Left XY Joint Assembly.step, 3030 Right XY Joint Assembly.step, 3030 X Axis Assembly.step]
2026-09-22 Update README.md
    specified linear rail types
2026-09-22 Delete UserMods/WolfKnifeLaserBacon/3030_Monolith/Standard Monolith Assemblies/3030 Monolith - Standard - Assembled.step
    rail naming correction
    [3030 Monolith - Standard - Assembled.step]
2026-10-07 Update subassemblies
    [X_carriage.step, X_endstop.step, Y_endstop.step]
2026-10-08 Flatten STEP structure
    [V2_Z_idler_spacer.step, X_carriage.step, X_endstop.step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]
2026-10-21 Added stainless steel tube option
2026-11-07 Printed and sheet metal update: per-station files, round bearing seats, flat DXFs
    - Round bearing seats in the printed XY joints, motorless mounts, rear mounts
    and double-shear housings
    - Simpler printed rear mounts: counterbored stepper screws, fourth
    double-shear housing screw removed with its nut and washer
    - VT NP spacers replace the indexing ribs on the printed VT mounts
    - Sheet metal V2 mount plates take the standard 40 x 9 mm belt clamp instead
    of the hybrid Z-belt clips (clips moved to STLs/Legacy)
    - Updated printed Z joint NP spacer
    - Per-station CAD (Front_left, Front_right, Rear_left, Rear_right, XY_left,
    XY_right, Z_joint) replaces the old paired subassembly files
    - Frame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
2026-11-07 Drop the numbered folder names
    - CAD/V_Belt_paths is now CAD/Belt_path and CAD/XI_Frames is now
    CAD/Extrusions, without the number prefixes in the file names
    - Docs/I_X_axes is now Docs/X_axis
    - Old CAD/VII_Y_endstop and CAD/VIII_X_endstop removed, CAD/X_endstop and
    CAD/Y_endstop replace them
    - New split view render and README update

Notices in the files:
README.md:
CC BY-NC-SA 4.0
